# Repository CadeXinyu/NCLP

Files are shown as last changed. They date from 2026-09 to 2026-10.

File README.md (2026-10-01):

# Neural Closed-Loop Platform (NCLP)

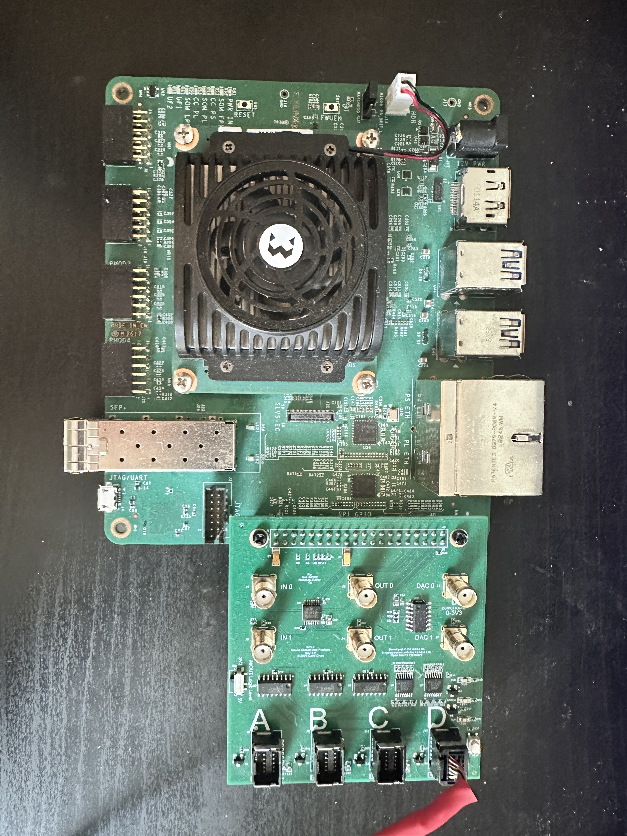
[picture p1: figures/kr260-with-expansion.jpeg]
NCLP hardware


NCLP is a neural data-acquisition and synchronization module for the AMD Kria
KR260. It coordinates data across the system, runs lightweight FPGA algorithms
for low-latency stimulation, and currently includes a ripple detector. It can
also stream data over SFP+ to another Xilinx FPGA for additional processing.

| Feature | Parameter |
| --- | --- |
| FPGA | AMD Kria KR260/K26 (`xck26-sfvc784-2LV-c`) |
| Acquisition | Intan RHD; 5, 10, 15, 20, 25, or 30 kS/s |
| Digital I/O | 2 TTL inputs and 2 TTL outputs |
| Analog output | 2-channel, 12-bit DAC |
| SFP+ | Aurora 64B/66B at 10.3125 Gb/s |
| Tools | Vivado and Vitis 2025.1 |

## Architecture

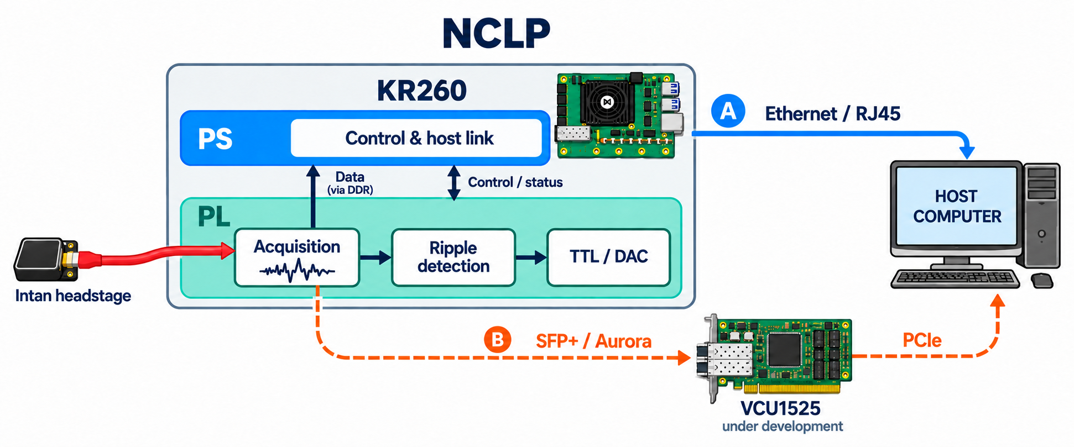
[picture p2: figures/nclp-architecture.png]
NCLP system architecture


The PL handles Intan acquisition, local ripple detection, and TTL/DAC output;
the PS provides control and Ethernet host communication (A). The SFP+/Aurora
path (B) supports streaming to an external FPGA for future processing workloads,
such as ML inference or spike sorting. VCU1525 integration is under development.

## Build

```bash
python3 scripts/build_ripple_hls.py
vivado -mode batch -source scripts/create_project.tcl
vivado -mode batch -source scripts/build_bitstream_export_once.tcl
vitis -s scripts/create_vitis_platform.py
vitis -s scripts/create_vitis_main.py
(cd vitis_project/main && bootgen -arch zynqmp -image boot.bif -o BOOT.bin -w on)
```

## Latency

Latency is the physical TTL time minus the detector's causal threshold-crossing
time. The fixed-cycle FPGA path provides deterministic low latency without
software scheduling jitter.

| System | Reported latency | Measurement |
| --- | ---: | --- |
| NCLP FPGA (theoretical) | 1.23 µs | Causal detector sample to TTL; fixed 123 clocks with 0-cycle RTL jitter |
| NCLP Intan TTL loopback, 100 trials | One 33.3 µs sample bin | Ideal replay decision to returned TTL; 100/100 in the same bin |
| [Dutta, Ackermann, and Kemere (2019)](https://doi.org/10.1088/1741-2552/aae90e), Intan + SpikeGadgets Ethernet | 1.35–2.60 ms for 80% of trials | Ideal simulated detection to online looped-back trigger |
| [Dutta, Ackermann, and Kemere (2019)](https://doi.org/10.1088/1741-2552/aae90e), Intan + Open Ephys USB | 7.5–13.8 ms for 80% of trials | Same method |
| [SpikesPeak](https://neuralascension.com/spikespeak/develop/RecordingTests/CLOSED_LOOP_LATENCY.html), Neuropixels 2.0 ASAP | 0.546–0.608 ms median | Online threshold to physical stimulation; p95: 0.66–0.72 ms |
| [SpikesPeak](https://neuralascension.com/spikespeak/develop/RecordingTests/CLOSED_LOOP_LATENCY.html), Neuropixels 1.0 ASAP | 0.942–0.977 ms median | Online threshold to physical stimulation; p95: 1.08–1.13 ms |

For the physical test, the DAC generates a 150–250 Hz ripple burst in saline and
an Intan probe records it. The TTL output is looped back to an Intan TTL input
and recorded with the probe data. Offline replay identifies the causal detector
time; latency is the returned TTL time minus that reference. The Intan TTL input
is sampled every 33.3 µs, so this test cannot resolve or match the theoretical
1.23 µs path.

## Open Ephys

The Open Ephys GUI 1.1.0 plugin is in `open-ephys/NCLPIntanSource/`.

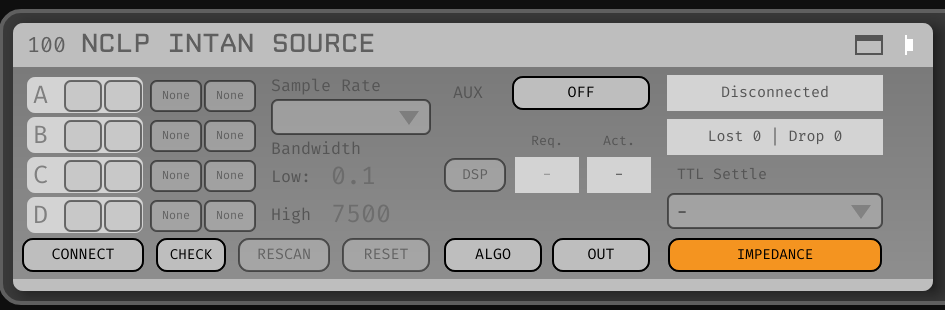
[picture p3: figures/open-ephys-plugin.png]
NCLP Open Ephys plugin


## PCB

The open-source expansion PCB is designed to fit Intan headstages.

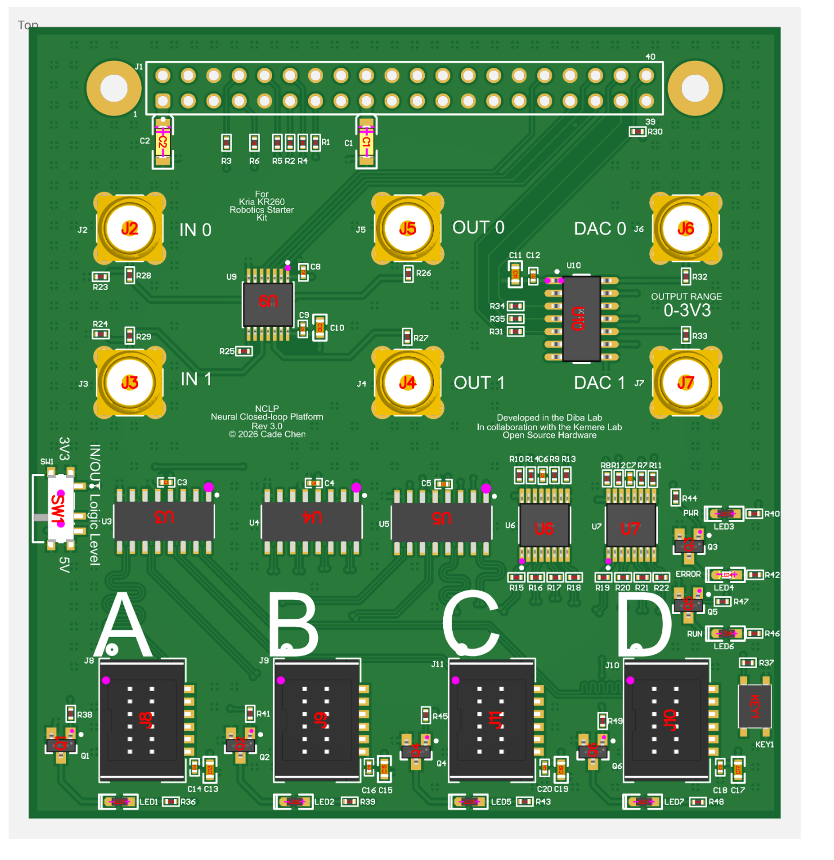
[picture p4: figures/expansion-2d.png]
NCLP expansion PCB


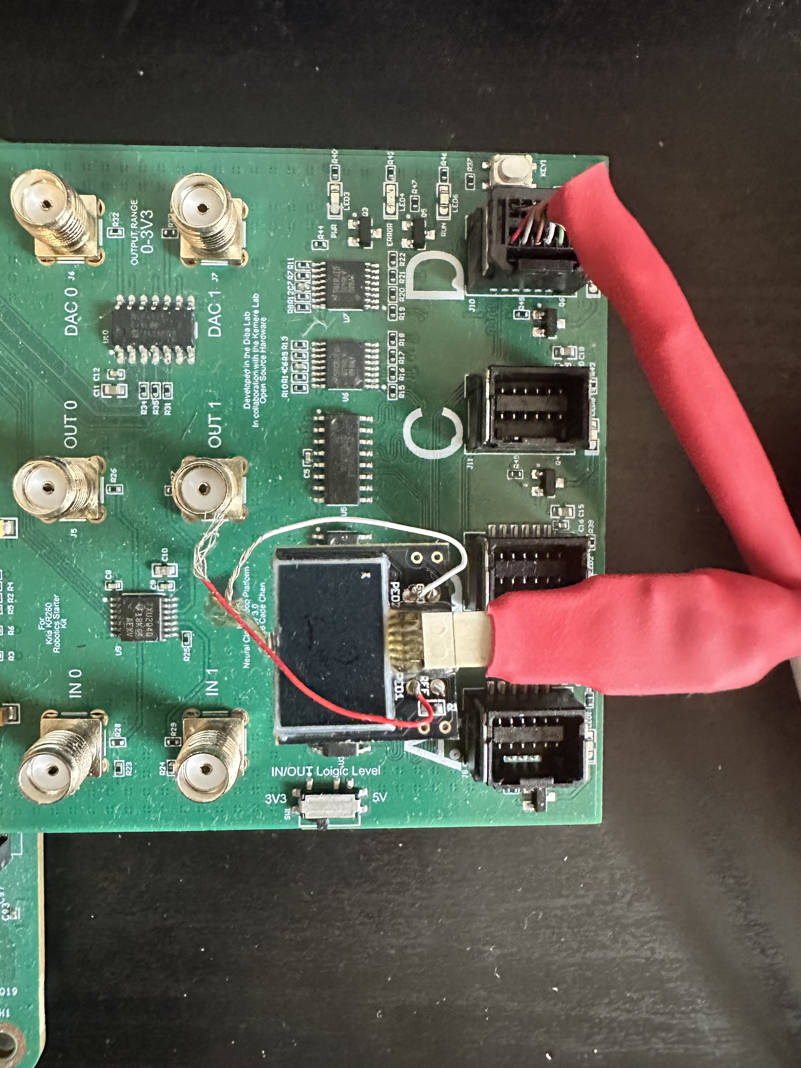
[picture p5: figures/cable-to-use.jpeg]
Cable to use


## License

Original NCLP source and design files are available under the [MIT License](LICENSE).
Third-party components retain their original terms; see
[Third-Party Notices](THIRD_PARTY_NOTICES.md). The Open Ephys plugin remains
GPL-3.0-or-later, as do firmware binaries containing the GPL-derived impedance
implementation.

## References

- Ankit Sethi and Caleb Kemere, “[Real time algorithms for sharp wave ripple detection](https://doi.org/10.1109/EMBC.2014.6944164),” *EMBC*, 2014.
- Shayok Dutta, Etienne Ackermann, and Caleb Kemere, “[Analysis of an open source, closed-loop, realtime system for hippocampal sharp-wave ripple disruption](https://doi.org/10.1088/1741-2552/aae90e),” *Journal of Neural Engineering*, 2019.
- [SpikesPeak closed-loop latency measurements](https://neuralascension.com/spikespeak/develop/RecordingTests/CLOSED_LOOP_LATENCY.html).
- Intan and FPGA design references: [LLNSP](https://github.com/chongxi/LLNSP), [MicroZedIntanInterface](https://github.com/kemerelab/MicroZedIntanInterface), and [GLANCE Neuro](https://github.com/glanceneuro/glance-neuro).
- Open Ephys references: [GLANCE plugin](https://github.com/glanceneuro/glance-neuro-plugin), [Acquisition Board](https://github.com/open-ephys-plugins/acquisition-board), and [RHD Recording Controller](https://github.com/open-ephys-plugins/rhd-recording-controller).
- Ethernet RTL reference: [verilog-ethernet](https://github.com/alexforencich/verilog-ethernet).

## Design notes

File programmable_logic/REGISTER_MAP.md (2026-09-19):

# NCLP programmable-logic register maps

This document describes the current cleaned contracts for the project-owned
AXI-Lite blocks. All registers are 32-bit and all offsets are byte offsets. The
previous register layouts are not retained. Each block reports its own ABI
version as listed below.
The four BD subsystems are capture, compute, stimulation and platform. Capture,
compute and stimulation expose project-owned AXI-Lite controls. The SFP packet
mailbox is a separate project-owned AXI-Lite peripheral in the compute group.

The Zynq `pl_ps_irq0` input is a three-bit, active-high level vector:

| Bit | Source | Deassertion |
| --- | --- | --- |
| 0 | Intan-to-DDR transfer IRQ, Intan error, or stimulation fault | ACK/clear each pending source |
| 1 | Compute-fabric fault | Clear the fabric diagnostic source or disable its fault IRQ |
| 2 | SFP packet-mailbox interrupt | Pop RX data, clear TX completion, or clear the enabled mailbox error |

The public `NCLP_PL_IRQ_*` constants specify these bit positions. Production
firmware must service the fabric and mailbox independently. The TTL
router does not add an IRQ bit. Use the generated BSP/OS interrupt mapping when
registering handlers. [AMD PG201](https://docs.amd.com/r/en-US/pg201-zynq-ultrascale-plus-processing-system/Programmable-Logic-Clocks-and-Interrupts)

Each owned block begins with the same identity header:

| Offset | Register | Meaning |
|---:|---|---|
| `0x00` | `BLOCK_ID` | Four-byte ASCII block identity |
| `0x04` | `ABI_VERSION` | Major/minor ABI version |
| `0x08` | `CAPABILITIES` | Implemented optional features |
| `0x0C` | `INFO` or block-specific `LIMITS` | Fixed geometry or limits |

Software verifies `BLOCK_ID`, the ABI major, the required capability subset,
and the `0x0C` geometry/limits word where the block defines it. Reserved or unaligned reads return zero
and writes have no effect.

| Block | PS base | Aperture | ABI | `BLOCK_ID` | `INFO` |
|---|---:|---:|---:|---:|---:|
| Intan SPI | `0x80000000` | 64 KiB | v3 | `0x494E544E` (`INTN`) | `0x10100400` |
| DDR circular writer | `0x80010000` | 4 KiB | v2 | `0x44445257` (`DDRW`) | `0x00100802` |
| LED control | `0x80011000` | 4 KiB | v2 | `0x4C454453` (`LEDS`) | `0x00000605` |
| Stimulation/DAC | `0x80012000` | 8 KiB | v3 | `0x5354494D` (`STIM`) | `0x02040400` |
| TTL output router | `0x80014000` | 4 KiB | v2 | `0x54544C52` (`TTLR`) | `0x00040202` |
| Ripple detector | `0x80020000` | 4 KiB | v3 | `0x52505754` (`RPWT`) | `0x001E0100` |
| Compute fabric | `0x80021000` | 4 KiB | v4 | `0x4E434650` (`NCFP`) | reserved (`0`) |
| SFP packet mailbox | `0x80030000` | 4 KiB | v2 | `0x4E504D42` (`NPMB`) | `0x00280040` |

Firmware constants are in `software/common/nclp_pl_registers.h`. The maps group
lifecycle commands/status, configuration, runtime results, diagnostics, and
memory windows by function. Redundant identity/state readbacks are removed;
all live controls and safety diagnostics remain. Retired register addresses
have no compatibility aliases. Unassigned addresses remain
inert. Drivers compare ABI majors with `NCLP_ABI_MAJOR_MASK` and check their
required capability subset. The compute fabric owns Intan destination selection,
local decoding, SFP packet routing, trigger validation, and diagnostics. Aurora
transport has no register bank. The packet mailbox owns fixed PS command/reply
queues without accessing DDR; the capture writer is the only PL DDR master.
STIM remains the only owner of DAC configuration and status.

## Intan SPI v3

ABI v3 exposes two independently enabled copies of one compact raw stream:
`M_AXIS_RECORDING` for the DDR writer and `M_AXIS_COMPUTE` for the compute
router. It removes the dedicated 64-bit sample output. All memory windows and
live diagnostics remain.

The two outputs preserve identical 16-bit payload words. On `M_AXIS_COMPUTE`,
the final TTL word of each complete frame carries `TKEEP=0b11, TLAST=1` so the
compute switch knows the raw frame boundary. The selected SFP packetizer buffers
the complete frame before output. Recording keeps payload `TLAST=0`. Both outputs mark session EOS with
`TKEEP=0b00, TLAST=1`.

The Intan block is one flat PS-visible ABI. There is no command mailbox and no
second internal register-ID map. Register accesses are direct 32-bit MMIO, and
three direct windows expose all AUX command RAM banks.

| Offset | Register | Access | Meaning |
|---:|---|---|---|
| `0x00-0x0C` | Identity header | RO | `INTN`, ABI `0x00030000`, capabilities `0x3FF`, geometry |
| `0x10` | `ACQUISITION_COMMAND` | W1P | bit 0 `START`; reads zero |
| `0x14` | `ACQUISITION_STATUS` | RO | running, START pending, access locked, START rejected |
| `0x20` | `ACQUISITION_CONFIG` | RW | bit 0 continuous, bit 1 DSP settle, bit 2 init dummy |
| `0x24` | `FINITE_FRAME_COUNT` | RW | complete 32-bit finite frame count |
| `0x28` | `LOGICAL_STREAM_ENABLE` | RW | enabled logical streams `[15:0]` |
| `0x2C` | `OUTPUT_CONFIG` | RW | bit 0 recording output, bit 1 compute output |
| `0x30` | `MISO_PHASE_PRIMARY` | RW | eight packed 4-bit primary-lane phases |
| `0x34` | `MISO_PHASE_SECONDARY` | RW | eight packed 4-bit secondary-lane phases |
| `0x40` | `SAMPLE_CLOCK_COMMAND` | W1P | bit 0 `APPLY`; reads zero |
| `0x44` | `SAMPLE_CLOCK_CONFIG` | RW | O `[7:0]`, D `[11:8]`, M `[18:12]` |
| `0x48` | `SAMPLE_CLOCK_STATUS` | RO | locked, ready, busy, error, error code `[6:4]` |
| `0x50/0x54/0x58` | `AUX1_BANK_SELECT/END_INDEX/LOOP_INDEX` | RW | bank fields `[7:0]`, inclusive end `[9:0]`, loop start `[9:0]` |
| `0x60/0x64/0x68` | `AUX2_BANK_SELECT/END_INDEX/LOOP_INDEX` | RW | same fields for AUX2 |
| `0x70/0x74/0x78` | `AUX3_BANK_SELECT/END_INDEX/LOOP_INDEX` | RW | same fields for AUX3 |
| `0x80` | `FAST_SETTLE_CONFIG` | RW | enable bit 0; channel `[7:4]` |
| `0x90` | `SYNC_MODE` | RW | 0 off, 1 periodic, 2 recording gate |
| `0x94` | `SYNC_PERIOD_FRAMES` | RW | periodic-sync period in complete sample frames |
| `0x98` | `SYNC_HIGH_FRAMES` | RW | periodic-sync high time in complete sample frames |
| `0xA0` | `OUTPUT_STATUS` | RO | source loss, recording session end seen, recording active/stall |
| `0xA4` | `DIAGNOSTIC_COMMAND` | W1P | bit 0 clears output diagnostics/counters; reads zero |
| `0xA8/0xAC` | `RECORDING_PAYLOAD_WORD_COUNT_LO/HI` | RO | accepted 16-bit recording payload-word count |
| `0xB0` | `RECORDING_END_OF_SESSION_MARKER_COUNT` | RO | accepted recording end-of-session markers |
| `0xB4` | `UNACCEPTED_SOURCE_EVENT_COUNT` | RO | source events rejected by an enabled output |
| `0xB8` | `RECORDING_STALL_CYCLE_COUNT` | RO | SPI-source clock cycles stalled by recording backpressure |
| `0xC0` | `ERROR_STATUS` | RO/W1C | sticky incident vector |
| `0xC4` | `ERROR_ENABLE` | RW | interrupt-enable vector |
| `0xC8` | `ERROR_INCIDENT_COUNT` | RO | total recorded incidents |
| `0xCC` | `LAST_ERROR_CODE` | RO | most recent incident code |
| `0xE0/0xE4` | `STREAM_SOURCE_MAP_LO/HI` | RO | fixed logical-to-physical source descriptor `0xF7E6D5C4_B3A29180` |

`CAPABILITIES` bit assignments are: flat register map (0), recording output
stream (1), compute output stream (2), periodic sync (3), recording gate (4), error
IRQ (5), coherent stimulation marker (6), direct AUX windows (7), AUX RAM
readback (8), and coherent START snapshot (9).

`START` is accepted only when at least one logical stream is enabled,
configuration is unlocked, both prior output paths and their EOS markers have
drained, either continuous mode is set or
`FINITE_FRAME_COUNT` is nonzero, every AUX `LOOP_INDEX <= END_INDEX`, and the
sync mode/timing tuple is valid, with no active clock-manager error. An accepted
request waits if the sample clock is temporarily not ready. When recording output is
enabled, the DDR writer must be armed before software writes
`ACQUISITION_COMMAND.START`; compute-only sessions leave the writer idle.
DSP settle, init dummy, finite
count, stream mask, output routing, both full phase words, AUX selection and
indices, fast settle, sync configuration, and the stimulation marker mask join
one coherent START snapshot. The continuous bit remains live so clearing it can
request a clean frame-boundary stop.

To change sample rate, write the complete packed O/D/M value to
`SAMPLE_CLOCK_CONFIG`, write `SAMPLE_CLOCK_COMMAND.APPLY`, observe BUSY, and
wait for BUSY to clear with READY and LOCKED set and ERROR clear. APPLY is
accepted while stopped and then held BUSY until both output FIFOs and pending
end markers have drained; only then may the clock manager reset the SPI clock
domain. The supported tuples all use D=4:
`(O,M)=(80,32),(40,32),(30,36),(20,32),(16,32),(15,36)`.

Periodic sync is defined in frames:

```text
frequency = Intan sample rate / SYNC_PERIOD_FRAMES
duty      = SYNC_HIGH_FRAMES / SYNC_PERIOD_FRAMES
```

Period and high time must be nonzero and high must not exceed period. Recording
gate is high only while recording.

The 64-KiB aperture assigns these direct AUX command windows:

| Offset range | Contents |
|---:|---|
| `0x4000-0x7FFC` | AUX1 banks A-D |
| `0x8000-0xBFFC` | AUX2 banks A-D |
| `0xC000-0xFFFC` | AUX3 banks A-D |

Each window contains four banks of 1024 16-bit commands. Command `(bank,index)`
is addressed at `window + (bank * 1024 + index) * 4`. Reads return the stored
16-bit command in bits `[15:0]`. Writes are rejected while configuration is
locked or acquisition is active.

`ERROR_STATUS` bits 0 through 6 are source-event loss, recording stall, rejected AUX
write, rejected START, rejected sample-clock request, rejected control write,
and sample-clock failure. `LAST_ERROR_CODE` uses 0 for none and 1 through 7 in
that same order. The error-enable reset value enables source-event loss and
sample-clock failure. A runtime clock failure aborts the SPI domain without an
EOS marker; the sticky clock-failure IRQ tells software to abort the paired DDR
session. A successful later APPLY is the supported clock-recovery path.
Diagnostic CLEAR requests use a request/acknowledge CDC handshake; a second
CLEAR while the first is still pending is rejected as a control-write error.

## DDR circular writer v2

Software programs shadow geometry, then issues START to accept it atomically.
`CONSUMED_BLOCK_COUNT` is the single live RW absolute consumer count; it is not
START-latched. ABI v2 removes its duplicate readback and the duplicate numeric
state field from STATUS. No old-address aliases are provided.

| Offset | Register group | Access | Meaning |
|---:|---|---|---|
| `00-0C` | Identity header | RO | `DDRW`, ABI v2, capabilities `0x0F`, geometry |
| `10` | `COMMAND` | W1P | START, ABORT, SOFT_RESET, IRQ_ACK, SNAPSHOT |
| `14` | `STATUS` | RO | run/data/IRQ/EOS/fault flags; bits `[31:14]` reserved |
| `18` | `SESSION_STATE` | RO | explicit numeric state |
| `1C` | `SESSION_ID` | RO | increments on accepted START |
| `20/24` | `RING_BASE_ADDR_LO/HI` | RW | DDR ring base |
| `28` | `RING_SIZE_BYTES` | RW | total extent; checked against block size × capacity |
| `2C` | `BLOCK_SIZE_BYTES` | RW | fixed consumer slot size |
| `30` | `RING_CAPACITY_BLOCKS` | RW | number of slots |
| `34` | `IRQ_COMPLETION_INTERVAL_BLOCKS` | RW | produced-block IRQ interval |
| `40/44` | `CURRENT_WRITE_ADDR_LO/HI` | RO | active session write address |
| `48` | `CURRENT_WRITE_OFFSET_BYTES` | RO | offset relative to active ring base |
| `4C/50` | `LAST_PRODUCED_BLOCK_ADDR_LO/HI` | RO | last committed block address |
| `54` | `LAST_PRODUCED_BLOCK_SIZE_BYTES` | RO | bytes in last committed block |
| `60` | `CONSUMED_BLOCK_COUNT` | RW | absolute released-block count; cannot exceed produced count |
| `64` | `PRODUCED_BLOCK_COUNT` | RO | committed blocks |
| `68` | `OUTSTANDING_BLOCK_COUNT` | RO | produced minus consumed |
| `6C` | `FINAL_BLOCK_SIZE_BYTES` | RO | exact terminal block size |
| `70/74` | `FIFO_LEVEL_ENTRIES/FIFO_HIGH_WATER_ENTRIES` | RO | live occupancy and peak |
| `80` | `ERROR_STATUS` | RO/W1C | sticky error vector |
| `84` | `LAST_AXI_BRESP` | RO | most recent AXI write response |
| `88` | `INPUT_PROTOCOL_ERROR_COUNT` | RO | rejected malformed input events |
| `A0-A8` | Transfer diagnostics | RO | backpressure cycles and 64-bit DDR-committed bytes |
| `C0-D0` | Coherent snapshot | RO | sequence, produced, consumed, outstanding, final-block size |

`COMMAND` bits 0 through 4 are START, ABORT, SOFT_RESET, IRQ_ACK, and
SNAPSHOT. `ERROR_STATUS` bits 0 through 7 are data loss, invalid configuration,
AXI write-response error, session abort, input protocol, invalid address, reset
during a session, and rejected START. IRQ acknowledgement and W1C error clearing
are separate operations. SNAPSHOT captures the accounting fields together;
reset, accepted START and SOFT_RESET invalidate the snapshot to zero.

Capabilities identify 16-beat bursts, the internal FIFO, fixed consumer slots,
and end-of-stream handling. `INFO` encodes 16 maximum AXI beats, 8 bytes per
AXI beat, and 2 bytes per input AXIS beat.

## LED control v2

| Offset | Register | Access | Meaning |
|---:|---|---|---|
| `00-0C` | Identity header | RO | `LEDS`, ABI v2, capabilities `0x07`, geometry |
| `10` | `SOFTWARE_ON_MASK` | RW | logical-on bits for A, B, C, D, error LED |
| `14` | `STATUS` | RO | physical active-high outputs `[5:0]` (A, B, C, D, error, running); hardware-error input bit 6 |

One status word exposes both physical levels and the hardware-error source;
the latter distinguishes a fault override from a software-requested error LED.
The duplicated telemetry registers at `40/44` are unmapped. Hardware faults always
light the error LED and cannot be hidden by `SOFTWARE_ON_MASK`. `running`
directly follows the synchronized SPI-running indication.

## Stimulation/DAC controller v3

Stimulation control is independent of Intan acquisition. An external trigger
rising edge can start a timed TTL pulse or MCP4922 playback only while armed;
the safety-gated trigger monitor and raw Intan sync may be routed to physical
TTL pins for observation without ARM. The compute trigger mux chooses either
the local `ripple_detector` request or the validated SFP trigger request as
the external trigger; reset selects the local source. RTL/C fields use
`EXTERNAL_TRIGGER_ENABLE` and `TRIGGER_MONITOR` for this generic input.
An external pulse that arrives while a timed TTL action or DAC playback is
already active is not queued. The controller ignores that pulse as an action
and increments `UNSERVED_TRIGGER_COUNT`, while `ERROR_STATUS.TRIGGER_DROPPED`
(bit 6) becomes sticky. The detector continues processing samples and counts its own emitted requests
independently of STIM acceptance. Continuous DAC playback accepts its first
trigger and drops later detector requests until playback stops.
The active-low, pull-up hardware button locally forces stimulation safe-off without
resetting Intan, the selected raw sync route, configuration, or waveform RAM.
It shares DISARM and retains a completed PRIME, allowing ARM again after release
and zeroing; an unfinished PRIME is cancelled.

| Offset | Register | Access | Meaning |
|---:|---|---|---|
| `00-0C` | Identity header | RO | `STIM`, ABI v3 (`0x00030000`), capabilities `0x7EF`, RAM geometry |
| `10` | `COMMAND` | W1P | ARM, DISARM, software trigger, STOP_ACTIVITY, CLEAR_DIAGNOSTICS, PRIME_DAC |
| `14` | `STATUS` | RO | live arm, activity, clock and fault state; bits 9, 10 and 13 reserved |
| `18` | `ACCEPTED_TRIGGER_COUNT` | RO | accepted stimulation actions |
| `1C` | `UNSERVED_TRIGGER_COUNT` | RO | controller-rejected triggers, DAC-domain UNSERVED acknowledgements, and waveform aborts |
| `20` | `ACTION_CONFIG` | RW | OFF/TTL/DAC action and external-trigger enable |
| `24` | `TTL_PULSE_WIDTH_AXI_CYCLES` | RW | generated timed-TTL or DAC companion-pulse length in 100 MHz AXI clocks; zero disables a DAC companion |
| `28` | `INTAN_STIM_MARKER_MASK` | RW | recorded marker mask for logical TTL `[15:2]` |
| `40-54` | DAC playback preset | RW | channel enable, continuous mode, update period, indices, finite count |
| `60-68` | DAC playback status | RO | prime state, waveform index, completed-update count |
| `70` | `SAFETY_STATUS` | RO | safe-off active and seen bits |
| `74` | `SAFE_OFF_COUNT` | RO | saturating debounced press count |
| `80` | `ERROR_STATUS` | RO/W1C | sticky incident vector |
| `84` | `FAULT_IRQ_ENABLE` | RW | fault IRQ mask |
| `88/8C` | Error history | RO | saturating incident-cycle count and the most recent complete incident vector |
| `A0` | `DAC_CLOCK_CONFIG` | RW | DAC PLL O, D, M tuple |
| `A4/A8` | `DAC_CLOCK_COMMAND/STATUS` | W1P/RO | program; locked/ready/busy |
| `1000+4*n` | `WAVEFORM[n]` | RW | packed B `[27:16]`, A `[11:0]` codes |

The register groups are lifecycle/outcomes (`10-1C`), output action (`20-28`),
DAC playback (`40-68`), safety (`70-74`), diagnostics (`80-8C`), clock (`A0-A8`),
and waveform RAM (`1000+`). Unmapped words, including `30-3C`, read zero and
ignore writes. All live safety and diagnostic registers remain implemented.

The `1024 x 32` dual-clock BRAM stores paired A/B codes. `COMMAND.PRIME_DAC`
validates and snapshots the preset, then writes hard zero to both DAC channels.
An accepted action, waveform-RAM, DAC-playback, or DAC-clock change invalidates
that prime and requires a new `PRIME_DAC` command.
Every accepted trigger starts at START and wraps END back to LOOP. Finite
completion, STOP, DISARM, and hardware safe-off finish an accepted SPI
frame/pair and then write zero to both A and B. Cleanup zero frames are not
counted as waveform updates. Reset and an interrupted DAC-clock epoch retain a
mandatory A/B-zero request and execute it when a valid DAC clock returns; DAC
PRIME/ARM remain inhibited until that recovery finishes. `STATUS.BUSY` remains
set for the full obligation, even while the DAC clock is unavailable.

The 14-bit Intan marker output is an event interface: the mask stays stable for
the event and `intan_marker_active` denotes the accepted TTL/DAC event envelope.
For DAC it includes the short request/prelaunch interval and terminal A/B-zero
cleanup; a hardware safe-off press drops it immediately. The Intan block owns
the marker CDC and frame-boundary application. Priming is not marker activity.
Intan running never locks stimulation configuration and DISARM never waits for
acquisition to stop. Waveform accesses must be word-aligned; zero-`WSTRB`
writes are true no-ops and do not invalidate PRIME.

STIM owns the source levels presented to the router. `stimulus_level` is the
timed pulse gated low during safe-off. `trigger_monitor_level` follows the
selected external trigger, gated low during safe-off and held-trigger recovery.
A trigger held high through safe-off remains suppressed until it returns low
after release; a low source while the button is held cannot clear suppression.
Both levels are combinationally gated, with no added output clock cycle.
`CAPABILITIES[8]` (`STIM_CAP_TRIGGER_MONITOR`) advertises monitor ownership.
`configuration_locked` protects action settings and drives the router's
`route_write_locked` input. Internal safety state is not a router input.

STIM no longer reads Intan running/sync levels or owns physical pin routing.
Its `STATUS[13,10,9]` and `ERROR_STATUS[0]` are reserved zero. The implemented
error mask is `0x1FE` and the reset fault IRQ mask is `0x3E`. Pin routing cannot
veto ARM/PRIME: a timed pulse can be generated with no physical pin selected,
and a TTL route error cannot stop an otherwise valid DAC action.

## TTL output router v2

The router has its own AXI slave at `0x80014000` and retains its configuration
independently of stimulus settings. It accepts `stimulus_level` and
`trigger_monitor_level` already gated by STIM, raw `intan_sync` from capture,
and `route_write_locked` from STIM's configuration lock. It owns pin mapping and
route diagnostics; it has no safe-off input or monitor-recovery state.

| Offset | Register | Access | Meaning |
|---:|---|---|---|
| `00-0C` | Identity header | RO | `TTLR`, ABI v2 (`0x00020000`), capabilities `0xB`, INFO `0x00040202` |
| `10` | `ROUTE` | RW | TTL0 selector `[1:0]`, TTL1 selector `[3:2]`; reset OFF/OFF |
| `14` | `STATUS` | RO | route-write lock, conflict and source/output levels; bits 1 and 3 reserved zero |
| `18` | `ERROR_STATUS` | RO/W1C | bit 0 blocked route write; bit 1 invalid route write |

Capabilities are source mux (bit 0), raw Intan sync (bit 1), and route-write
protection (bit 3). Bit 2 is no longer a safety capability.

Each selector is 0 OFF, 1 stimulation level, 2 raw Intan sync, or 3 trigger-monitor
level. Duplicate non-OFF selections set live conflict and force both pins low;
OFF/OFF is valid. Route validity is independent of the stimulus action mode.
Only byte strobe 0 updates `ROUTE`; reserved bits are masked. While
`route_write_locked` is high, route writes are ignored and record a blocked-write
error. This input never gates the selected levels or changes an existing route.
Invalid route writes store the route and set the invalid-route error. New errors
win simultaneous W1C. Reserved/unaligned accesses and zero-strobe writes have no
effect. The router exposes no interrupt.

`STATUS` bit 0 is `ROUTE_WRITE_LOCKED`, bit 2 `ROUTE_CONFLICT`, `[5:4]` sampled
physical TTL levels, bit 6 sampled Intan sync, bit 7 `STIMULUS_LEVEL`, and bit 8
`TRIGGER_MONITOR_LEVEL`. Bits 1 and 3 are reserved zero. The source level bits
reflect the gated inputs; safety diagnostics remain in STIM. Async telemetry
uses two-flop synchronizers, while physical routing stays combinational. A valid
Intan-sync route continues during safe-off because STIM does not gate that source.

## Ripple detector v3

The selected-channel HLS detector uses fixed-point internal arithmetic.
Configuration and threshold telemetry retain IEEE-754 binary32 register words;
reported power is a raw unsigned 32-bit integer mean square. It uses
fixed 11-tap `/2` and minimum-phase 120-tap `/5` anti-alias filters, followed by
a selectable ripple FIR or fourth-order IIR and PWT.
It requires hardware-verified 30 kS/s acquisition; its working rate is 3 kS/s.
`LIMITS` encodes 30 maximum PWT samples in `[31:16]` and 256 maximum ripple
FIR taps in `[15:0]`.

| Offset | Register | Access | Meaning |
|---:|---|---|---|
| `00-0C` | Identity header | RO | RPWT, ABI `0x00030000`, capabilities `0x1FF`, LIMITS `0x001E0100` |
| `10` | `COMMAND` | WO | `STOP=0`; `START=1`; `VALIDATE=2`; `RESTORE_DEFAULTS=4`; reads zero |
| `14` | `STATUS` | RO | bits 0 enabled, 1 busy, 2 config valid, 3 rate valid, 4 waiting stream, 5 session closed, 6 fault, 7 write rejected, 8 warmup |
| `20` | `INPUT_CHANNEL_ID` | RW | stream `[8:5]`, amplifier channel `[4:0]`; range 0..511 |
| `24` | `FILTER_KIND` | RW | 0 FIR (default); 1 fourth-order IIR, two normalized biquads |
| `28` | `FIR_TAP_COUNT` | RW | configured ripple FIR length, 1..256; default 129 |
| `2C` | `POWER_WINDOW_US` | RW | PWT duration, 1..10000 us; default 4000 us |
| `30` | `REFRACTORY_PERIOD_MS` | RW | interval after an accepted crossing; default 1000 ms |
| `34` | `BASELINE_MEAN_BITS` | RW | baseline RMS mean, binary32 ADC counts |
| `38` | `BASELINE_STDDEV_BITS` | RW | baseline RMS standard deviation, binary32 ADC counts |
| `3C` | `THRESHOLD_K_BITS` | RW | nonnegative finite binary32 threshold multiplier; default 4; supports live update |
| `40` | `COEFFICIENT_INDEX` | RW | FIR index 0..255; IIR coefficients 256..265 |
| `44` | `COEFFICIENT_BITS` | RW | indexed binary32 coefficient upload; commits and reads back the last HLS-accepted word |
| `50` | `TRIGGER_REQUEST_COUNT` | RO | detector trigger requests, independent of downstream acceptance |
| `54` | `POWER_SAMPLE_COUNT` | RO | processed 3 kS/s power outputs |
| `58` | `MEAN_SQUARE` | RO | latest mean square, raw uint32 in ADC counts squared |
| `5C` | `SUM_SQUARE_THRESHOLD_BITS` | RO | validated `N * (mean + K * stddev)^2`, binary32 |
| `60` | `LAST_INPUT_TIMESTAMP` | RO | newest selected-channel input timestamp |

This table is the internal PL ABI. The public firmware profile accepts filter
kinds 0 minimum-phase FIR, 1 linear-phase FIR, and 2 fixed IIR. Firmware maps
both FIR choices to hardware `FILTER_KIND=0` and uploads the designed taps; it
maps the IIR choice to `FILTER_KIND=1`. Public control uses
`RIPPLE_APPLY_PROFILE`; there is no public coefficient-upload or VALIDATE
command. Firmware admits the complete profile only after acquisition is stopped
and drained in `IDLE` or `READY`, and preflights all scalar values plus the
designed filter before issuing any PL write. `RIPPLE_SET_K` remains the only
public live detector-configuration update. Baseline START instead requires the
active 30 kS/s local/UDP detector stream; the raw SFP route bypasses this block.

Except for live `THRESHOLD_K_BITS`, parameters and coefficients are writable only while disabled and HLS-idle;
changes invalidate `CONFIG_VALID`. VALIDATE recomputes threshold/configuration
without starting acquisition. START clears detector state and enables only after
successful HLS validation. A coefficient write is staged until its HLS update
completes. Nonfinite or fixed-point-unrepresentable coefficients set
`WRITE_REJECT` and leave the previous accepted `COEFFICIENT_BITS` readback unchanged.
Invalid baseline parameters or geometry remain disabled and report a fault.
STOP mutes triggers immediately.

An enabled detector accepts a full-word `THRESHOLD_K_BITS` write while a sample is processing.
One update can be queued, and `BUSY` includes that queue. HLS applies the new
threshold between transactions without resetting histories, power-window fill,
edge state, counters or refractory timing. `THRESHOLD_K_BITS` and
`SUM_SQUARE_THRESHOLD_BITS` commit after
successful validation. A rejected update sets `WRITE_REJECT` and preserves the
previous threshold and enabled state. A concurrent STOP, EOS or rate loss
cancels an uncommitted update. Lowering K can cause a crossing on the next power
sample. Firmware exposes this operation as `RIPPLE_SET_K`.

IIR indices 256..260 and 261..265 each contain `b0,b1,b2,a1,a2`, with `a0=1`.
For each section, `y=b0*x+b1*x1+b2*x2-a1*y1-a2*y2`. Validation rejects nonfinite
coefficients or poles outside the strict stable region. The default is a
four-pole Butterworth bandpass at 150..250 Hz, sampled at 3 kS/s. Custom
coefficients determine the band and response. Capability bits 0 through 8
respectively denote FIR, IIR, programmable coefficients, input-channel
selection, configurable power window, refractory control, live K updates,
uint32 mean-square reporting, and fixed-point internal DSP.

The PWT evaluates RMS against `baseline_mean + K * baseline_stddev` using a
sum-of-squares comparison.
Host software supplies baseline statistics in that RMS domain. The default
4 ms window contains 12 samples at 3 kS/s. Configuration, selected-channel
history, window warmup, and refractory timing belong to the detector. STIM owns
all later playback, acceptance, ARM, busy rejection, and safe-off behavior.

Internally, `S=sum(x^2)` and the trigger compares the exact 64-bit sum against
`N*(baseline_mean+K*baseline_stddev)^2`. `MEAN_SQUARE` reports the rounded
integer mean `S/C`, where
`C` is the current valid-sample count during warmup and `N` afterward. The
reported value is bounded by `32768^2` and does not scale with window length.

See [algorithm-module.md](../docs/algorithm-module.md) for the DSP chain and HLS
build contract. A stopped detector or ended acquisition does not cancel an
already accepted stimulation action.

## Compute fabric v4

The compute fabric accepts the compact 16-bit Intan compute stream and sends it
exclusively to the local decoder or the raw SFP packetizer. It also arbitrates
Intan and PS mailbox packets onto Aurora, strips target-2 RX headers, and
validates the one target-3 trigger command. Aurora/CDC and the AXI-Lite mailbox
are separate components.

The block is at `0x80021000`, identifies as `NCFP`, and uses ABI v4. Its
capabilities value `0x3F` represents local decoding, raw Intan SFP transport, PS
packet routing, SFP stimulation trigger, AUX events, and TTL events.

| Group | Offset | Register | Access | Meaning |
| --- | ---: | --- | --- | --- |
| Identity | `00` | `BLOCK_ID` | RO | `0x4E434650` (`NCFP`) |
| Identity | `04` | `ABI_VERSION` | RO | `0x00040000` |
| Identity | `08` | `CAPABILITIES` | RO | `0x0000003F` |
| Configuration | `10` | `CONTROL` | RW | bit 0 PHY enable, bit 1 SFP application-mode select, bit 8 fault IRQ enable |
| Configuration | `14` | `SOURCE_STREAM_MASK` | RW | exact nonzero logical-stream mask `[15:0]` for local decode |
| Command | `18` | `COMMAND` | W1P | bit 0 clear diagnostics; bit 1 clear the Intan EOS latch |
| Status | `20` | `STATUS` | RO | mode, drain, queue, fault, and EOS state below |
| Status | `24` | `LINK_STATUS` | RO | bit 0 link up, bit 1 link fault, bit 2 RX parser idle |
| Diagnostics | `30` | `CONTROL_REJECT_COUNT` | RO | rejected reserved/unsafe configuration or command writes |
| Diagnostics | `34` | `LOCAL_DECODE_FAULT_COUNT` | RO | malformed or truncated local frames |
| Diagnostics | `38` | `SFP_PACKETIZER_FAULT_COUNT` | RO | malformed, truncated, or overlength raw frames dropped by the SFP packetizer |
| Diagnostics | `3C` | `SFP_TX_INTERRUPTED_PACKET_COUNT` | RO | SFP TX packets interrupted after payload transmission began |
| Diagnostics | `40` | `RX_MALFORMED_PACKET_COUNT` | RO | invalid header or payload framing |
| Diagnostics | `44` | `RX_FIFO_OVERFLOW_COUNT` | RO | target-2 packet storage overflow |
| Diagnostics | `48` | `RX_DROPPED_PACKET_COUNT` | RO | packets for unknown/unsupported targets |
| Diagnostics | `4C` | `PS_RX_PACKET_COUNT` | RO | complete target-2 packets committed to PS |
| Diagnostics | `50` | `RX_STIM_TRIGGER_COUNT` | RO | accepted target-3 stimulation-trigger commands |
| Diagnostics | `54` | `RX_STIM_TRIGGER_REJECT_COUNT` | RO | rejected target-3 stimulation-trigger commands |
| Diagnostics | `58` | `INTAN_TX_PACKET_ENQUEUED_COUNT` | RO | complete raw Intan packets enqueued into the TX CDC |
| Diagnostics | `5C` | `PS_TX_ATTEMPT_ENQUEUED_COUNT` | RO | complete PS TX attempts enqueued into the TX CDC |

`CONTROL` resets to `0x00000101`: PHY and fault IRQ enabled, local compute
selected. Only bits 0, 1, and 8 are writable. A mode change is rejected unless
`CONFIG_IDLE` is set. PHY and IRQ state may be updated without changing the
mode. `SOURCE_STREAM_MASK` resets to `1`; zero, upper-bit writes, and a changed
mask while not configuration-idle are rejected.

PS routing is fixed in hardware. Every reply uses target 2, EOM set, and protocol
version 1, producing header `0x0000000000000182`.

`COMMAND.CLEAR_DIAGNOSTICS` clears sticky fault state and all fabric/RX counters.
An incident in the clear cycle is still counted. `CLEAR_INTAN_EOS` clears
`STATUS.INTAN_EOS_SEEN` and is accepted only while configuration-idle. A new
compute-stream active edge also clears that EOS bit; an accepted zero-keep Intan
TLAST sets it.

| STATUS bit | Meaning |
| ---: | --- |
| 0 | qualified physical link up |
| 1 | PHY enabled |
| 2 | SFP application mode selected |
| 3 | Intan compute-output session active |
| 4 | configuration idle |
| 5 | local decoder inside a frame |
| 6 | raw SFP packetizer inside a frame |
| 7 | SFP TX arbiter idle |
| 8 | Intan TX packet active |
| 9 | PS TX packet pending or active |
| 10 | complete PS RX data pending |
| 11 | local decode fault sticky |
| 12 | raw SFP packetizer fault sticky |
| 13 | interrupted SFP TX packet sticky |
| 14 | RX route/framing/overflow/trigger fault sticky |
| 15 | rejected control write sticky |
| 16 | Intan session EOS accepted |

The compute IRQ is active when fault IRQ is enabled and either physical
`link_fault` is live or any sticky bit 11 through 15 is set. PS packet
availability and mailbox completion/error state use PL IRQ bit 2.

### Local algorithm event format

The local decoder snapshots the full stream mask at frame start and emits:

```text
[63:32] timestamp
[31:30] kind: 0 AMP, 1 AUX reply, 2 TTL
[29:25] flags = 0
[24:21] sparse logical stream ID
[20:16] channel 0..31 or AUX slot 0..2
[15:0]  value
```

AMP and AUX events use full keep without TLAST. The TTL event uses full keep and
TLAST. Session EOS is zero-keep TLAST. The local stream begins before the full
raw frame has arrived.

### SFP packet header and targets

Every physical AXIS64 packet starts with one full-keep, non-TLAST header:

```text
[63:16] reserved = 0
[15:8]  protocol version = 1
[7]     end of logical message (EOM)
[6:0]   target ID
```

Targets are 1 for a raw Intan frame, 2 for PS data, and 3 for the stimulation trigger
request. Target-1 packets always set EOM and contain the exact compact Intan
frame, grouped four 16-bit words per payload beat. The magic, timestamp, all 35
rows, and TTL are unchanged. The source mask is not inserted into the packet.
The final payload beat uses the contiguous low-byte TKEEP appropriate for one to
four remaining halfwords. The packetizer buffers the complete frame, up to 567
halfwords, before output; malformed, truncated, and overlength frames emit no
partial packet.

PS-to-card payload comes from the fixed packet mailbox; the fabric adds header
`0x0182`. Card-to-PS target-2 packets require EOM and version 1. The RX router
strips the header before delivering payload to the mailbox. Intan and PS packets
are arbitrated round-robin and never interleaved.

Target 3 accepts only one full-keep payload word equal to `1`, with EOM set and
SFP mode selected. It emits one trigger pulse. DAC waveform, preset, PRIME,
ARM, STOP, DISARM, and status remain exclusively in the STIM AXI-Lite block.

## SFP packet mailbox v2

The project-owned `NPMB` block is mapped at `0x80030000` with a 4 KiB aperture.
It has two packet slots in each direction and no DDR master. RX accepts exactly
eight full AXIS64 beats with `TLAST` on beat eight, stores one 64-byte canonical
command atomically, and exposes the front command as sixteen 32-bit AXI-Lite
words. TX snapshots ten 32-bit staging words into one 40-byte reply and emits
five full AXIS64 beats. Software uses `RX_POP` after copying a command and
`TX_COMMIT` after filling the reply window.

| Group | Offset | Register | Access | Meaning |
| --- | ---: | --- | --- | --- |
| Identity | `00` | `BLOCK_ID` | RO | `0x4E504D42` (`NPMB`) |
| Identity | `04` | `ABI_VERSION` | RO | `0x00020000` |
| Identity | `08` | `CAPABILITIES` | RO | `0x0000003F` |
| Identity | `0C` | `INFO` | RO | `0x00280040`: TX 40 bytes, RX 64 bytes |
| Status | `10` | `STATUS` | RO | queue, link, Aurora acceptance, replay, and error state below |
| Interrupt | `14` | `IRQ_ENABLE` | RW | bit 0 RX available, bit 1 TX accepted by Aurora, bit 2 error |
| Command | `18` | `COMMAND` | W1P | bit 0 RX pop, bit 1 TX commit, bit 2 clear Aurora-accepted status, bit 3 clear diagnostics |
| Error | `1C` | `ERROR_STATUS` | RW1C | malformed RX, RX overflow, empty pop, full TX commit, TX feedback errors |
| Counter | `20` | `RX_PACKET_COUNT` | RO | commands committed into RX slots |
| Counter | `24` | `RX_OVERFLOW_COUNT` | RO | complete commands dropped because both RX slots were full |
| Counter | `28` | `RX_MALFORMED_COUNT` | RO | wrong RX payload length, TLAST position, or TKEEP |
| Counter | `2C` | `TX_AURORA_ACCEPTED_COUNT` | RO | replies whose final PS-owned beat was accepted by the local Aurora TX interface |
| Counter | `30` | `TX_REJECT_COUNT` | RO | TX commits rejected because both slots were full |
| Counter | `34` | `TX_REPLAY_COUNT` | RO | interrupted replies retained for replay |
| RX window | `40..7C` | `RX_DATA[0..15]` | RO | front 64-byte command; stable until RX pop, zero when empty |
| TX window | `80..A4` | `TX_DATA[0..9]` | RW | 40-byte staging reply snapshotted by TX commit |

`STATUS` uses bit 0 RX available, bit 1 RX full, bit 2 TX space available,
bit 3 TX pending, bit 4 TX output valid, bit 5 link up, bit 6 TX accepted-by-Aurora sticky,
bit 7 TX replay pending, bits `[9:8]` RX count, bits `[11:10]` TX count, and
bit 12 error pending. `ERROR_STATUS` uses bit 0 RX malformed, bit 1 RX overflow,
bit 2 RX pop while empty, bit 3 TX commit while full, and bit 4 unexpected TX
acceptance/interruption feedback. `ERROR_STATUS` is write-one-to-clear.
`CLEAR_DIAGNOSTICS` clears all six counters while preserving those W1C errors.

The mailbox IRQ is level-high for any enabled RX-available, TX-Aurora-accepted, or
error condition. A reply remains queued until the transport reports that the
local Aurora TX interface accepted its final PS-owned beat. This is a local
completion event, not an acknowledgment from the remote card. Link interruption
rewinds the reply for a complete replay rather than publishing its tail as a new
packet.

Firmware automatically selects compute `CONTROL.SFP_MODE_SELECT` and enables SFP
command ingress only when the full usable-link predicate is true: both ABIs are
valid, compute reports `LINK_STATUS.UP` without `LINK_STATUS.FAULT`, and the
mailbox reports synchronized `STATUS.LINK_UP`. That state gives SFP ownership of
commands, replies, and the raw stream while muting RJ45 command execution and
UDP output. A raw `link_up` bit alone is insufficient. lwIP maintenance and the
RJ45 ownership-banner listener continue while Ethernet application traffic is
muted.

See [`docs/aurora-link-v1.md`](../docs/aurora-link-v1.md) for the wire contract.

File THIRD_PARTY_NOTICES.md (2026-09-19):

# Third-Party Notices

The top-level MIT License applies only to original NCLP contributions. The
following components retain their existing copyright and license terms:

- `open-ephys/NCLPIntanSource/` is based in part on the
  [GLANCE Open Ephys plugin](https://github.com/glanceneuro/glance-neuro-plugin)
  and Open Ephys plugin code. It is distributed under GPL-3.0-or-later; its
  full license is included in that directory and under `LICENSES/`.
- `software/main/src/headstage/impedance_headstage.c` adapts impedance
  processing from the Open Ephys RHD Recording Controller and is distributed
  under GPL-3.0-or-later. Firmware binaries that incorporate this file are
  subject to the GPL; the full license is included under `LICENSES/`.
- `programmable_logic/src/spi/fifo/axis_async_fifo.v` is Copyright (c)
  2014–2023 Alex Forencich and is licensed under the MIT License. Its complete
  notice is retained in the file.
- The fixed decimation coefficients under
  `programmable_logic/hls/ripple_detector/` derive from
  [GLANCE Neuro](https://github.com/glanceneuro/glance-neuro), Copyright (c)
  2025–2026 Caleb Kemere and Rice University, under the MIT License. The
  source notices are retained in the generated files.
- AMD and Xilinx generated or vendor files retain their per-file copyright
  and license notices.
- `PCB/12pin/5054331271.SchLib` contains an Ultra Librarian component model
  with its own copyright notice and is excluded from the top-level MIT grant.

Nothing in the top-level license overrides these terms or any copyright and
license notice contained in an individual file.

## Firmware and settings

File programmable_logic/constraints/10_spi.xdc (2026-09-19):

# Intan SPI interface constraints for KR260/K26
# Board/pin source: reference/kr260.xdc and reference/pi_header.txt
# Top-level source: NCLP_wrapper generated from the current block design.

# Intan SPI interface on KR260 Raspberry Pi header, LVCMOS33.
set_property -dict {PACKAGE_PIN AG14 IOSTANDARD LVCMOS33 SLEW FAST DRIVE 8} [get_ports sclk]
set_property -dict {PACKAGE_PIN W14  IOSTANDARD LVCMOS33 SLEW FAST DRIVE 8} [get_ports cs]
set_property -dict {PACKAGE_PIN W13  IOSTANDARD LVCMOS33 SLEW FAST DRIVE 8} [get_ports mosi_a]
set_property -dict {PACKAGE_PIN Y14  IOSTANDARD LVCMOS33 SLEW FAST DRIVE 8} [get_ports mosi_c]
set_property -dict {PACKAGE_PIN AB14 IOSTANDARD LVCMOS33 SLEW FAST DRIVE 8} [get_ports mosi_b]
set_property -dict {PACKAGE_PIN AB9  IOSTANDARD LVCMOS33 SLEW FAST DRIVE 8} [get_ports mosi_d]

set_property -dict {PACKAGE_PIN Y9   IOSTANDARD LVCMOS33} [get_ports miso_a1]
set_property -dict {PACKAGE_PIN AE13 IOSTANDARD LVCMOS33} [get_ports miso_a2]
set_property -dict {PACKAGE_PIN AC13 IOSTANDARD LVCMOS33} [get_ports miso_b1]
set_property -dict {PACKAGE_PIN AA8  IOSTANDARD LVCMOS33} [get_ports miso_b2]
set_property -dict {PACKAGE_PIN AF13 IOSTANDARD LVCMOS33} [get_ports miso_c1]
set_property -dict {PACKAGE_PIN AC14 IOSTANDARD LVCMOS33} [get_ports miso_c2]
set_property -dict {PACKAGE_PIN AH13 IOSTANDARD LVCMOS33} [get_ports miso_d1]
set_property -dict {PACKAGE_PIN AH14 IOSTANDARD LVCMOS33} [get_ports miso_d2]

# Pack the SPI output launch registers into the I/O boundary when legal. This
# reduces fabric-to-pad routing delay and output skew for the source-synchronous
# Intan SPI bus.
set_property IOB TRUE [get_ports sclk]
set_property IOB TRUE [get_ports cs]
set_property IOB TRUE [get_ports mosi_a]
set_property IOB TRUE [get_ports mosi_b]
set_property IOB TRUE [get_ports mosi_c]
set_property IOB TRUE [get_ports mosi_d]

# Keep unplugged MISO inputs from floating during bring-up. Remove these if the
# external Intan adapter board already has stronger biasing.
set_property PULLTYPE PULLDOWN [get_ports miso_a1]
set_property PULLTYPE PULLDOWN [get_ports miso_a2]
set_property PULLTYPE PULLDOWN [get_ports miso_b1]
set_property PULLTYPE PULLDOWN [get_ports miso_b2]
set_property PULLTYPE PULLDOWN [get_ports miso_c1]
set_property PULLTYPE PULLDOWN [get_ports miso_c2]
set_property PULLTYPE PULLDOWN [get_ports miso_d1]
set_property PULLTYPE PULLDOWN [get_ports miso_d2]

# The FPGA pins drive external LVCMOS-to-LVDS interface devices. SLEW FAST is
# an electrical output-buffer choice; the constraints below provide the
# package-I/O timing contract used for implementation.
#
# Reference all SPI package paths to the surviving output-BUFG clock object. The
# default/faster profile is 84 MHz; runtime reconfiguration only slows it to
# 70/56/42/28/14 MHz. SCLK is registered data from this clock (a 21 MHz
# waveform at the fastest profile), not a clock-tree endpoint, so do not create
# a generated clock on the SCLK output port.
set spi_clock_pin [get_pins -quiet -hierarchical -filter \
    {NAME =~ */spi_clkgen/u_output_buffer/u_output_bufg/O}]
set spi_sampling_clock [get_clocks -quiet -of_objects $spi_clock_pin]

# Provisional external-interface allowance. Until measured transmitter,
# receiver, PCB, cable, and Intan setup/hold limits are available, use the
# Glance-style package bounds agreed for bring-up: every outbound SPI signal
# has +2 ns max / -2 ns min relative to spi_clk.
set spi_driven_outputs [get_ports {sclk cs mosi_a mosi_b mosi_c mosi_d}]
set_output_delay -clock $spi_sampling_clock -max 2.000 $spi_driven_outputs
set_output_delay -clock $spi_sampling_clock -min -2.000 $spi_driven_outputs

# MISO is captured on all four quarter-SCLK phases and the valid phase is
# selected per lane at runtime. Constrain the package-to-sampler paths with the
# agreed provisional 0.5 ns earliest / 3.0 ns latest arrival window. The much
# larger external round-trip latency remains handled by lane phase calibration;
# these values must be replaced after the complete interface is measured.
set spi_sampled_inputs [get_ports {
    miso_a1 miso_a2 miso_b1 miso_b2
    miso_c1 miso_c2 miso_d1 miso_d2
}]
set_input_delay -clock $spi_sampling_clock -max 3.000 $spi_sampled_inputs
set_input_delay -clock $spi_sampling_clock -min 0.500 $spi_sampled_inputs

# Do not false-path this interface. The build audit deliberately fails if any
# critical SPI port loses its I/O-delay coverage or an invalid generated clock
# is introduced.

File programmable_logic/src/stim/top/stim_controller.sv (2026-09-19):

`timescale 1ns / 1ps
`default_nettype none

module stim_controller #(
    parameter integer C_S00_AXI_DATA_WIDTH = 32,
    parameter integer C_S00_AXI_ADDR_WIDTH = 13,
    parameter integer RAM_DEPTH = 1024,
    parameter integer RAM_ADDR_WIDTH = (RAM_DEPTH > 1) ? $clog2(RAM_DEPTH) : 1,
    parameter integer DAC_CLKS_PER_HALF_BIT = 2,
    parameter integer DAC_CS_SETUP_CLKS = 1,
    parameter integer DAC_CS_HOLD_CLKS = 1,
    parameter integer DAC_CS_HIGH_CLKS = 4,
    parameter integer SAFE_OFF_RELEASE_DEBOUNCE_CYCLES = 1_000_000,
    parameter integer SIM_CLOCK_BYPASS = 0
)(
    input  wire                                  stim_trigger,
    input  wire                                  force_safe_off_button_n,
    output wire                                  stimulus_level,
    output wire                                  trigger_monitor_level,
    output wire                                  configuration_locked,
    // The mask is a stable configuration payload; only the single-bit active
    // level is an event crossing into the Intan SPI clock domain.
    output reg                                   intan_marker_active,
    output wire [13:0]                           intan_marker_mask,
    output wire                                  stim_fault_irq,
    output wire                                  dac_sync_n,
    output wire                                  dac_sclk,
    output wire                                  dac_sdin,
    input  wire                                  clkgen_ref_clk,
    input  wire                                  sim_dac_clk,
    input  wire                                  sim_dac_clock_locked,
    input  wire                                  sim_dac_clock_ready,
    input  wire                                  sim_dac_clock_program_busy,
    input  wire                                  s00_axi_aclk,
    input  wire                                  s00_axi_aresetn,
    input  wire [C_S00_AXI_ADDR_WIDTH-1:0]       s00_axi_awaddr,
    input  wire [2:0]                            s00_axi_awprot,
    input  wire                                  s00_axi_awvalid,
    output wire                                  s00_axi_awready,
    input  wire [C_S00_AXI_DATA_WIDTH-1:0]       s00_axi_wdata,
    input  wire [(C_S00_AXI_DATA_WIDTH/8)-1:0]   s00_axi_wstrb,
    input  wire                                  s00_axi_wvalid,
    output wire                                  s00_axi_wready,
    output wire [1:0]                            s00_axi_bresp,
    output wire                                  s00_axi_bvalid,
    input  wire                                  s00_axi_bready,
    input  wire [C_S00_AXI_ADDR_WIDTH-1:0]       s00_axi_araddr,
    input  wire [2:0]                            s00_axi_arprot,
    input  wire                                  s00_axi_arvalid,
    output wire                                  s00_axi_arready,
    output wire [C_S00_AXI_DATA_WIDTH-1:0]       s00_axi_rdata,
    output wire [1:0]                            s00_axi_rresp,
    output wire                                  s00_axi_rvalid,
    input  wire                                  s00_axi_rready
);

    localparam [1:0] ACTION_MODE_OFF = 2'd0;
    localparam [1:0] ACTION_MODE_TTL = 2'd1;
    localparam [1:0] ACTION_MODE_DAC = 2'd2;
    // The implemented clock is statically timed at the 40 MHz default.  Runtime
    // programming may select slower legal tuples, but never a faster one.
    localparam integer DAC_ENGINE_MAX_MHZ = 40;

    wire safe_off_active;
    wire safe_off_event;
    stim_safe_off_button #(
        .RELEASE_DEBOUNCE_CYCLES(SAFE_OFF_RELEASE_DEBOUNCE_CYCLES)
    ) safe_off_button_i (
        .clk(s00_axi_aclk),
        .resetn(s00_axi_aresetn),
        .button_n_async(force_safe_off_button_n),
        .safe_off_active(safe_off_active),
        .safe_off_event(safe_off_event)
    );

    // Runtime-programmable DAC-engine PLL. Default: 140 MHz * 20/(2*35)
    // = 40 MHz. The playback shifter divides that by four for 10 MHz SCLK.
    wire dac_engine_clk;
    wire dac_clock_locked;
    wire dac_clock_ready;
    wire dac_clock_program_busy;
    wire dac_clock_error;
    wire [2:0] dac_clock_error_code;
    wire dac_clock_domain_reset_request;
    wire dac_domain_reset;
    wire dac_clock_program_pulse;
    wire [7:0] shadow_dac_clock_o;
    wire [3:0] shadow_dac_clock_d;
    wire [6:0] shadow_dac_clock_m;

    generate
        if (SIM_CLOCK_BYPASS != 0) begin : g_sim_clock
            assign dac_engine_clk = sim_dac_clk;
            assign dac_clock_locked = sim_dac_clock_locked;
            assign dac_clock_ready = sim_dac_clock_ready;
            assign dac_clock_program_busy = sim_dac_clock_program_busy;
            assign dac_clock_error = 1'b0;
            assign dac_clock_error_code = 3'd0;
            assign dac_clock_domain_reset_request = !s00_axi_aresetn ||
                                                    !sim_dac_clock_locked ||
                                                    !sim_dac_clock_ready ||
                                                    sim_dac_clock_program_busy;
        end else begin : g_real_clock
            plle4_clock #(
                .DEFAULT_O(8'd35),
                .DEFAULT_D(4'd2),
                .DEFAULT_M(7'd20)
            ) dac_clkgen (
                .config_clk(s00_axi_aclk),
                .source_clk(clkgen_ref_clk),
                .reset(!s00_axi_aresetn),
                .request(dac_clock_program_pulse),
                .config_valid(dac_clock_config_valid),
                .config_o(shadow_dac_clock_o),
                .config_d(shadow_dac_clock_d),
                .config_m(shadow_dac_clock_m),
                .ready(dac_clock_ready),
                .busy(dac_clock_program_busy),
                .done_pulse(),
                .error(dac_clock_error),
                .error_code(dac_clock_error_code),
                .locked(dac_clock_locked),
                .domain_reset_request(dac_clock_domain_reset_request),
                .domain_reset_ack(dac_domain_reset),
                .clock_out(dac_engine_clk)
            );
        end
    endgenerate

    // The manager requests reset before stopping or reprogramming the PLL. This
    // one XPM crossing makes assertion asynchronous to the DAC clock and release
    // synchronous to the restarted clock. The actual destination reset is fed
    // back so the manager cannot gate/restart the clock ahead of the DAC domain.
    xpm_cdc_async_rst #(
        .DEST_SYNC_FF(2),
        .INIT_SYNC_FF(0),
        .RST_ACTIVE_HIGH(1)
    ) dac_domain_reset_sync (
        .src_arst(dac_clock_domain_reset_request),
        .dest_clk(dac_engine_clk),
        .dest_arst(dac_domain_reset)
    );
    wire dac_domain_resetn = !dac_domain_reset;
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

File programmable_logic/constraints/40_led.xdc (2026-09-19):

# Active-high LED/light constraints for KR260/K26
# Board/pin source: reference/kr260.xdc and revised reference/Pins.png
# Top-level source: NCLP_wrapper generated from the current block design.
# All lights are active-high, so pull down keeps them off during configuration.

set_property -dict {PACKAGE_PIN AE15 IOSTANDARD LVCMOS33 SLEW SLOW DRIVE 4} [get_ports led_a]
set_property -dict {PACKAGE_PIN AE14 IOSTANDARD LVCMOS33 SLEW SLOW DRIVE 4} [get_ports led_b]
set_property -dict {PACKAGE_PIN AA12 IOSTANDARD LVCMOS33 SLEW SLOW DRIVE 4} [get_ports led_c]
set_property -dict {PACKAGE_PIN Y12  IOSTANDARD LVCMOS33 SLEW SLOW DRIVE 4} [get_ports led_d]
set_property -dict {PACKAGE_PIN AD14 IOSTANDARD LVCMOS33 SLEW SLOW DRIVE 4} [get_ports led_error]
set_property -dict {PACKAGE_PIN AD15 IOSTANDARD LVCMOS33 SLEW SLOW DRIVE 4} [get_ports running]

set_property PULLTYPE PULLDOWN [get_ports led_a]
set_property PULLTYPE PULLDOWN [get_ports led_b]
set_property PULLTYPE PULLDOWN [get_ports led_c]
set_property PULLTYPE PULLDOWN [get_ports led_d]
set_property PULLTYPE PULLDOWN [get_ports led_error]
set_property PULLTYPE PULLDOWN [get_ports running]

# Indicator outputs have no external synchronous receiver. Keep the exception
# at the package boundary; the internal LED/error logic remains timed.
set_false_path -to [get_ports {
    led_a led_b led_c led_d led_error running
}]

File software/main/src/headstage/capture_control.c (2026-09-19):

#include "headstage_internal.h"

static int ddr_capture_start(uint32_t block_bytes);

nclp_capture_context_t nclp_capture = {
    .ddr_capture_armed = 0U,
    .ddr_capture_active = 0U,
    .capture_valid_bytes = 0U,
    .capture_valid_words32 = 0U,
    .capture_block_bytes = SPI_CAPTURE_BLOCK_BYTES,
    .capture_ring_bytes = SPI_DDR_RING_BYTES,
    .capture_low_half_first = 0U,
};

uint16_t get_capture16(const uint32_t *words32, uint32_t index16, uint32_t low_half_first)
{
    uint32_t word = words32[index16 >> 1];

    if (low_half_first != 0U) {
        return (index16 & 1U) ? (uint16_t)(word >> 16) : (uint16_t)(word & 0xFFFFU);
    }

    return (index16 & 1U) ? (uint16_t)(word & 0xFFFFU) : (uint16_t)(word >> 16);
}

int magic_at_capture(const uint32_t *words32, uint32_t index16, uint32_t low_half_first)
{
    return (get_capture16(words32, index16 + 0U, low_half_first) == 0x1942U) &&
           (get_capture16(words32, index16 + 1U, low_half_first) == 0x2702U) &&
           (get_capture16(words32, index16 + 2U, low_half_first) == 0x1999U) &&
           (get_capture16(words32, index16 + 3U, low_half_first) == 0xC691U);
}

static uint32_t timestamp_at_capture(const uint32_t *words32, uint32_t index16, uint32_t low_half_first)
{
    uint32_t ts_lo = get_capture16(words32, index16 + 4U, low_half_first);
    uint32_t ts_hi = get_capture16(words32, index16 + 5U, low_half_first);

    return ts_lo | (ts_hi << 16);
}

void print_capture_word_order_debug(const char *label, uint32_t max_words32)
{
    uint32_t probe_words32 = (max_words32 > 8U) ? 8U : max_words32;
    uint32_t produced = reg_read(SPI_DDR_WRITER_BASE, DDRW_REG_PRODUCED_BLOCK_COUNT);
    uint32_t outstanding = reg_read(SPI_DDR_WRITER_BASE, DDRW_REG_OUTSTANDING_BLOCK_COUNT);
    uint32_t last_len = reg_read(SPI_DDR_WRITER_BASE, DDRW_REG_LAST_PRODUCED_BLOCK_SIZE_BYTES);
    uint32_t status = reg_read(SPI_DDR_WRITER_BASE, DDRW_REG_STATUS);
    uint32_t error = reg_read(SPI_DDR_WRITER_BASE, DDRW_REG_ERROR_STATUS);

    xil_printf("      INFO %s valid_words32=%lu valid_bytes=%lu order_guess=%lu\r\n",
               label,
               (unsigned long)probe_words32,
               (unsigned long)nclp_capture.capture_valid_bytes,
               (unsigned long)nclp_capture.capture_low_half_first);
    xil_printf("      INFO DDRW status=0x%08lx error=0x%08lx produced=%lu outstanding=%lu last_len=%lu\r\n",
               (unsigned long)status,
               (unsigned long)error,
               (unsigned long)produced,
               (unsigned long)outstanding,
               (unsigned long)last_len);
    for (uint32_t i = 0U; i < probe_words32; ++i) {
        xil_printf("      INFO cap32[%lu]=0x%08lx\r\n",
                   (unsigned long)i,
                   (unsigned long)nclp_capture.capture_ring_words[i]);
    }

    for (uint32_t order = 0U; order < 2U; ++order) {
        xil_printf("      INFO order=%lu magic=%lu ts=%lu words16=%04x %04x %04x %04x %04x %04x\r\n",
                   (unsigned long)order,
                   (unsigned long)magic_at_capture(nclp_capture.capture_ring_words, 0U, order),
                   (unsigned long)timestamp_at_capture(nclp_capture.capture_ring_words, 0U, order),
                   (unsigned int)get_capture16(nclp_capture.capture_ring_words, 0U, order),
                   (unsigned int)get_capture16(nclp_capture.capture_ring_words, 1U, order),
                   (unsigned int)get_capture16(nclp_capture.capture_ring_words, 2U, order),
                   (unsigned int)get_capture16(nclp_capture.capture_ring_words, 3U, order),
                   (unsigned int)get_capture16(nclp_capture.capture_ring_words, 4U, order),
                   (unsigned int)get_capture16(nclp_capture.capture_ring_words, 5U, order));
    }
}

uint32_t find_best_capture_order_and_offset(uint32_t stream_count,
                                                   uint32_t *best_order_out,
                                                   uint32_t *best_offset16_out)
{
    uint32_t words32_count = nclp_capture.capture_valid_words32;
    uint32_t frame_words16 = frame_words_for_stream_count(stream_count);
    uint32_t best_matches = 0U;
    uint32_t best_order = 0U;
    uint32_t best_offset16 = 0U;

    for (uint32_t order = 0U; order < 2U; ++order) {
        for (uint32_t offset16 = 0U; offset16 < frame_words16; ++offset16) {
            uint32_t matches = 0U;

            for (uint32_t frame = 0U; ; ++frame) {
                uint32_t index16 = offset16 + (frame * frame_words16);
                if ((index16 + frame_words16) > (words32_count * 2U)) {
                    break;
                }
                if (magic_at_capture(nclp_capture.capture_ring_words, index16, order)) {
                    matches++;
                }
            }

            if (matches > best_matches) {
                best_matches = matches;
                best_order = order;
                best_offset16 = offset16;
            }
        }
    }

    if (best_order_out != 0) {
        *best_order_out = best_order;
    }
    if (best_offset16_out != 0) {
        *best_offset16_out = best_offset16;
    }
    return best_matches;
}

uint32_t reg_read(uintptr_t base, uint32_t offset)
{
    return Xil_In32((UINTPTR)(base + offset));
}

void reg_write(uintptr_t base, uint32_t offset, uint32_t value)
{
    Xil_Out32((UINTPTR)(base + offset), value);
}

uint16_t rhd_convert_cmd(uint32_t channel)
{
    return (uint16_t)((channel & 0x3FU) << 8);
}

uint16_t rhd_read_reg_cmd(uint32_t reg)
{
    return (uint16_t)(0xC000U | ((reg & 0x3FU) << 8));
}

uint16_t rhd_write_reg_cmd(uint32_t reg, uint32_t value)
{
    return (uint16_t)(0x8000U | ((reg & 0x3FU) << 8) | (value & 0xFFU));
}

uint16_t rhd_calibrate_cmd(void)
{
    return 0x5500U;
}

uint16_t rhd_clear_cal_cmd(void)
{
    return 0x6A00U;
}

void intan_register_write(uint32_t reg_offset, uint32_t value)
{
    reg_write(INTAN_BASE, reg_offset, value);
}
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
